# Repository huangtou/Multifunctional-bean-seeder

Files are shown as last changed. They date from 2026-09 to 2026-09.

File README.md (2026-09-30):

# 🌱 多功能豆类播种机

<div align="center">

**基于 STM32F103 的智能履带式播种机 —— 集"行走 · 旋耕 · 开沟 · 播种 · 覆土 · 浇水"于一体**







</div>

---

## 📖 目录

- [项目简介](#-项目简介)
- [演示视频](#-演示视频)
- [项目展示](#-项目展示)
- [功能特性](#-功能特性)
- [整机结构](#️-整机结构)
- [硬件资源与引脚分配](#-硬件资源与引脚分配)
- [蓝牙遥控指令](#-蓝牙遥控指令)
- [软件设计](#-软件设计)
- [目录结构](#-目录结构)
- [快速上手](#-快速上手)
- [开发说明与已知问题](#-开发说明与已知问题)

---

## 📝 项目简介

传统人工播种效率低、株距不均。本项目设计了一款面向豆类作物的**小型多功能自动播种机**，由履带底盘搭载旋耕、开沟、精量排种、浇水等多套执行机构，以 STM32F103 为主控制器，通过蓝牙串口由手机 App 遥控作业，并具备限位开关与光电接近开关双重安全保护。

**主要指标**

| 项目 | 参数 |
| :--- | :--- |
| 主控制器 | STM32F103ZET6（正点原子精英板） |
| 主频 | 72 MHz |
| 行走方式 | 履带式双直流减速电机驱动 |
| 驱动方式 | 直流电机 PWM（10 kHz）+ A4988 步进驱动 |
| 通信方式 | 蓝牙串口 USART2 @ 9600 bps |
| 人机交互 | TFT LCD 实时状态显示 |
| 步进精度 | A4988 细分布进，每脉冲 0.1° |

---

## 🎬 演示视频

### 📺 [点击观看演示视频（B 站 BV14Pas6bEMW）](https://www.bilibili.com/video/BV14Pas6bEMW/?share_source=copy_web&vd_source=6c446a2c349afac65ccd988e4ed9c128)



---

## 🖼️ 项目展示

<table>
  <tr>
    <th align="center">三维模型（SolidWorks）</th>
    <th align="center">实物样机</th>
  </tr>
  <tr>
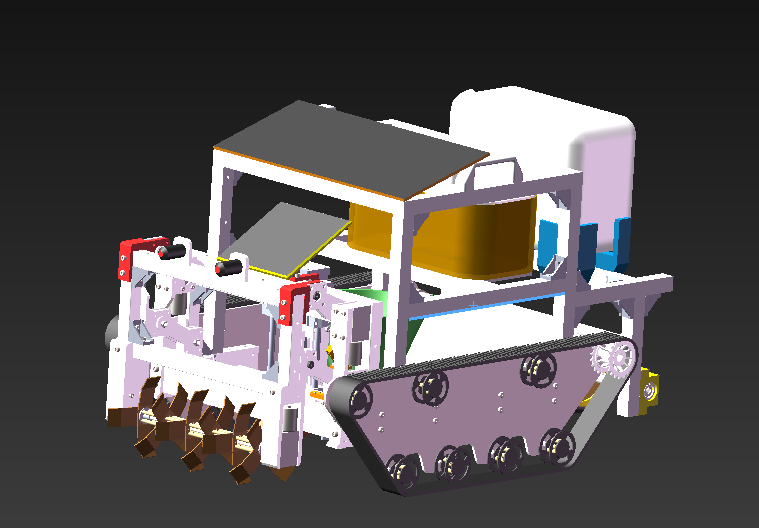
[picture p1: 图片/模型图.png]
三维模型图
    <td align="center"></td>
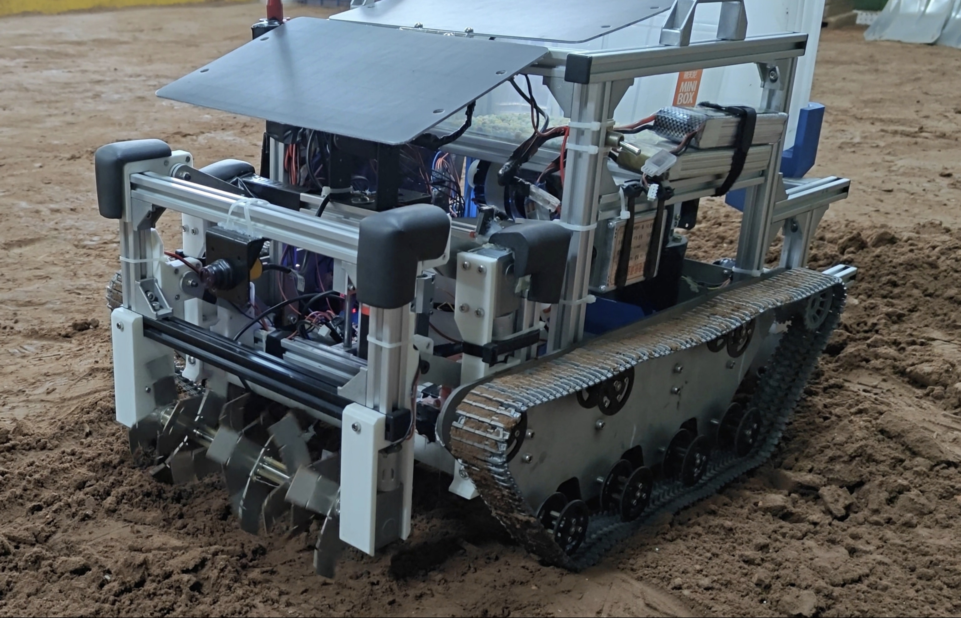
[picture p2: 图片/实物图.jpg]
实物样机图
    <td align="center"></td>
  </tr>
  <tr>
    <td align="center">整机装配体 <code>模型1/装配体.SLDASM</code></td>
    <td align="center">已加工装配完成并通过实地作业测试</td>
  </tr>
</table>

---

## ✨ 功能特性

- 🚜 **履带行走**：双路直流减速电机 + PWM 调速，支持前进 / 后退 / 左转 / 右转（差速转向）
- ⛏️ **旋耕碎土**：独立旋耕刀辊电机，同时可通过丝杆机构整体升降，适应不同耕作深度
- 🪓 **开沟起垄**：步进电机驱动的丝杆升降开沟器，落沟深度精确可控
- 🌰 **精量排种**：42 步进电机 + 组合播种器，由定时器节拍间歇转动实现定量播种
- 💧 **播种后浇水**：水泵 + 喷头 + 水箱机构，随播种同步开启
- 🔄 **覆土回填**：覆土板刮土回填沟槽，一次成型
- 📶 **蓝牙遥控**：手机 App 经 USART2 下发单字节指令，实时切换作业模式
- 🛡️ **多重限位保护**：3 路机械限位开关（PE0~PE2）+ 3 路光电接近开关（PD11~PD13），越程即停
- 🖥️ **状态可视化**：LCD 实时刷新各限位状态、接近开关状态与当前指令码

---

## 🏗️ 整机结构

SolidWorks 源文件位于 `模型1/`，按功能模块组织：

| 装配体文件 | 说明 |
| :--- | :--- |
| `装配体.SLDASM` | 整机总装 |
| `装配底盘.SLDASM` | 履带底盘、承重轮、主动轮、压紧轮 |
| `组合翻土轮.SLDASM` / `装配翻土轮.SLDASM` | 旋耕刀辊与升降保持架（丝杆 8X100 + 直线轴承） |
| `组合开沟器.SLDASM` / `装配开槽器.SLDASM` | 开沟头与升降架板 |
| `组合播种器.SLDASM` / `演示功能播种器.SLDASM` | 储种箱、存种盘、筛种盘、播种管道 |
| `组合浇水机构.SLDASM` | 水箱、水泵、喷头、吸/出水管 |
| `筛种盘/` | 含 4 张工程图（`.DWG`）与对应零件 |
| `装配体.STEP` | 通用 STEP 格式，**无需 SolidWorks 亦可查看** |
| `演示文稿1.pptx` | 项目汇报演示文稿 |

> 零件文件（`.SLDPRT`）共计 100 余个，涵盖机加工件、标准件与钣金件，均按功能命名，可直接用于出图加工。

---

## 🔌 硬件资源与引脚分配

### 主控板

**正点原子 STM32F103ZET6 精英板**（Flash 512 KB，SRAM 64 KB，工程宏：`STM32F10X_HD, USE_STDPERIPH_DRIVER`，启动文件 `startup_stm32f10x_hd.s`）

### 引脚分配总表

| 功能模块 | 方向 IO | PWM / 脉冲 | 说明 |
| :--- | :--- | :--- | :--- |
| **蓝牙串口** | PA2 (TX) / PA3 (RX) | — | USART2，9600 bps，接收中断 |
| **限位开关** | PE0 / PE1 / PE2 | — | 上拉输入，旋耕升降 / 开沟器行程终点检测 |
| **光电接近开关** | PD11 / PD12 / PD13 | — | 上拉输入，前后行进障碍物检测 |
| **履带左轮** | PB14 / PB15（INA） | PA0 — TIM2_CH1 | 直流减速电机正反转 + 调速 |
| **履带右轮** | PB13 / PB12（INB） | PA1 — TIM2_CH2 | 直流减速电机正反转 + 调速 |
| **旋耕器升降电机** | PA4 / PA5 | PA6 — TIM3_CH1 | 丝杆升降机构 |
| **旋耕刀辊电机** | PC4 / PC5 | PA7 — TIM3_CH2 | 旋耕碎土主电机 |
| **开沟器升降步进** | PC8 (STEP) / PC9 (DIR) | — | A4988 驱动器 |
| **播种步进电机** | PF14 (STEP) / PF15 (DIR) | — | A4988 驱动器 |
| **浇水水泵电机** | PF4 / PF5 | PA10 — TIM1_CH3 | 水泵启停 |
| **备用步进通道** | PF12/PF13、PC10/PC11 | — | 预留扩展 |
| **调试串口** | PA9 (TX) / PA10 (RX) | — | USART1 @ 9600，打印调试（⚠️ RX 脚 PA10 与水泵 PWM 复用，见文末「开发说明与已知问题」） |

> 完整 IO 说明亦见原始备份文件：`keil代码/README.TXT`

### 定时器资源分配

| 定时器 | 用途 | 配置 |
| :--- | :--- | :--- |
| TIM1 | 浇水水泵 PWM 输出 | 周期 8000-1，预分频 9-1 → 1 kHz |
| TIM2 | 左右履带电机 PWM | 同上 |
| TIM3 | 旋耕升降 / 旋耕刀辊 PWM | 同上 |
| TIM5 | 播种节拍定时中断 | 预分频 7200-1，周期 10000-1 → **1 s** 触发一次排种 |
| SysTick | `delay_ms()` / `delay_us()` 软件延时基准 | — |

---

## 📲 蓝牙遥控指令

主控串口 2 中断接收单字节数据存入 `temp1`，主循环据此切换作业状态：

| 指令值 | 动作 | 保护条件 |
| :---: | :--- | :--- |
| `0` | 使能播种定时器时钟 | — |
| `1` | 履带前进（双轮正转） | 前方光电开关检测到障碍（`gd1 == 0`）即停 |
| `2` | 履带后退（双轮反转） | 后方光电开关检测到障碍（`gd2 == 0`）即停 |
| `3` | **急停**：履带、旋耕、水泵、定时器全部停止 | — |
| `4` | 旋耕刀辊启动 | — |
| `5` | 旋耕器下降 | 触下限位（`num0 == 0`）自动停 |
| `6` | 旋耕器上升 | 触上限位（`num1 == 0`）自动停 |
| `7` | 浇水水泵启动 | — |
| `8` | 开沟器下降 | — |
| `9` | 开沟器上升 | 触上限位（`num2 == 0`）自动停 |
| `16` | 启动播种定时器（TIM5），进入定量排种节拍 | — |
| `17` | 左转（左轮反转 / 右轮正转） | — |
| `18` | 右转（左轮正转 / 右轮反转） | — |

**典型作业流程**

```
1 → 前进到作业区          → 3 停车
5 → 旋耕器下降至耕作深度  → 4 开启旋耕
8 → 开沟器下降至开沟深度  → 16 启动排种节拍
1 → 边前进边播种          → 7 同步浇水
9 / 6 → 作业结束收起机构  → 3 全部停止
```

---

## 💻 软件设计

### 主程序流程

```
main()
 ├─ delay_init()            延时基准初始化
 ├─ uart_init(9600)         USART1 调试串口
 ├─ LCD_Init()              TFT 屏初始化
 ├─ USART2_Init()           蓝牙串口 + 接收中断
 ├─ AIN_GPIO_Config / GENERAL_TIM_Init           ← TIM2 履带
 ├─ AIN_GPIO_Config2 / GENERAL_TIM_Init2         ← TIM3 旋耕
 ├─ AIN_GPIO_Config3 / GENERAL_TIM_Init3         ← TIM1 水泵
 ├─ MOTOR_Init()            A4988 步进 IO
 ├─ Xianwei_init()          限位开关 IO
 └─ while(1)
     ├─ 读取三路限位 + 两路光电 → LCD 实时显示
     └─ switch(temp1) 执行对应动作（含限位急停判断）
```

### 源码文件说明

| 文件 | 作用 |
| :--- | :--- |
| `USER/main.c` | 主循环状态机、传感器读取、LCD 显示、动作执行与安全互锁 |
| `USER/openmv.c/.h` | USART2 初始化与接收中断，蓝牙指令解码（**注：文件名为历史遗留，本项目实际接蓝牙模块**） |
| `USER/Motor_PWM.c/.h` | TIM2 履带双电机 PWM 驱动与正反转控制 |
| `USER/motor2.c/.h` | TIM3 旋耕升降 + 旋耕刀辊 PWM 驱动 |
| `USER/motor3.c/.h` | TIM1 水泵 PWM 驱动 |
| `USER/Stepper_A4988.c/.h` | A4988 步进脉冲生成，`Stepgo(电机号, 方向, 脉冲数)` |
| `USER/Stepper_motor.c` / `Stepper_motor2.c` | 备选的相序式步进驱动方案（当前未在主控流程中使用） |
| `USER/tim.c/.h` | TIM5 播种节拍中断，每次中断调用 `Stepgo(2, 0, 1500)` 排种 |
| `USER/xianwei.c/.h` | PE0~PE2 机械限位开关读取 |
| `USER/gd.c/.h` | PD11~PD13 光电接近开关读取 |
| `SYSTEM/delay`、`sys`、`usart` | 正点原子系统级延时、位带操作、调试串口 |
| `HARDWARE/LCD`、`LED`、`KEY` | TFT 显示、指示灯、按键外设驱动 |

### 步进电机驱动

`Stepgo(num, dir, step)` 通过 DIR 电平设定转向，再输出指定数量的 STEP 脉冲，脉冲宽度由 `delay_us()` 控制：

| 电机编号 | STEP / DIR | 用途 | 脉冲宽度 |
| :---: | :--- | :--- | :--- |
| 1 | PF12 / PF13 | 预留 | 200 µs |
| 2 | PF14 / PF15 | **播种排种** | 1000 µs |
| 3 | PC8 / PC9 | **开沟器升降** | 500 µs |
| 4 | PC10 / PC11 | 预留 | 1 ms |

### LCD 显示内容

LCD 上实时刷新 6 个状态量，方便现场排查传感器接线与机构到位情况：

```
限位0 / 限位1 / 限位2        ← PE0 / PE1 / PE2
当前指令 temp1               ← 蓝牙最新下发
光电1 / 光电2                ← PD11 / PD12
```

---

## 📁 目录结构

```
多功能豆类播种机/
├── 📄 README.md                 # 本说明文档
├── 📄 .gitignore                # 忽略编译产物与软件临时文件
│
├── 🖼️ 图片/                      # README 用图（模型渲染图、实物图）
├── 📷 样机照片/                  # 实物照片原图
│
├── 🎬 播种机演示视频.mp4         # 演示视频源文件（约 68 MB，建议不提交 Git）
│                                 #   在线观看：https://www.bilibili.com/video/BV14Pas6bEMW
│
├── 🧊 模型1/                     # SolidWorks 三维模型
│   ├── 装配体.SLDASM            # 整机总装
│   ├── 装配体.STEP              # 通用 STEP，无 SW 也可打开
│   ├── *.SLDPRT                 # 100+ 零件文件
│   ├── 筛种盘/                  # 含 DWG 工程图
│   └── 演示文稿1.pptx           # 项目汇报 PPT
│
└── 💾 keil代码/                  # STM32 Keil MDK 工程
    ├── USER/                    # 应用代码与工程文件（LCD.uvprojx）
    ├── HARDWARE/                # 外设驱动：LED / KEY / LCD
    ├── SYSTEM/                  # 系统底层：delay / sys / usart
    ├── STM32F10x_FWLib/         # ST 标准外设库
    ├── CORE/                    # 内核与启动文件
    ├── OBJ/                     # 编译输出（已 gitignore）
    └── README.TXT               # 原始 IO 与外设分配说明
```

---

## 🚀 快速上手

### 1. 编译与下载

1. 安装 **Keil MDK5**（需安装 STM32F1xx Device Family Pack）
2. 打开 `keil代码/USER/LCD.uvprojx`
3. Target Options → Device 选择 **STM32F103ZE**，C/C++ Define 保持 `STM32F10X_HD, USE_STDPERIPH_DRIVER`
4. 通过 **J-Link / ST-Link** SWD 接口连接板子，点击 Load 下载程序

### 2. 蓝牙连接

1. 蓝牙模块 TXD / RXD 交叉接至 **PA3(RX) / PA2(TX)**，波特率 **9600**（8N1，无流控）
2. 手机上打开蓝牙串口助手 App，配对模块
3. 以**十六进制 / 数值模式**发送上述指令码（如发送 `16` 启动排种流程图所示流程）

> ⚠️ 请勿以 ASCII 字符模式发送，代码按接收到的字节数值直接判别。

### 3. 查看三维模型

- 安装 SolidWorks：打开 `模型1/装配体.SLDASM`
- 无 SolidWorks：任意三维/CAD 软件打开 `模型1/装配体.STEP`

---

## ⚠️ 开发说明与已知问题

- **`openmv.c` 命名误导**：该文件实际实现的是 USART2 蓝牙接收，OpenMV 视觉模块并未接入，建议后续重命名为 `bluetooth.c`。
- **冗余文件**：`Stepper_motor.c` / `Stepper_motor2.c` 为早期 ULN2003 相序驱动方案，已被 A4988 方案替代，暂未从工程移除。
- **主循环阻塞**：`Stepgo()` 内部使用阻塞式 `delay_us()`，输出脉冲数较多时会长时间占用主循环，导致蓝牙指令响应延迟（如 `Stepgo(2,0,1500)` 约需 3 s）。建议改为定时器比较输出或 DMA 方式产生脉冲。
- **PA10 引脚冲突**：`uart_init()` 将 USART1_RX 配置在 PA10，而浇水水泵 PWM（TIM1_CH3）同样使用 PA10，两者存在复用冲突，实际测试中需二选一或重映射。
- **`GD_Value()` 返回值未全覆盖**：`i` 取其他值时函数无返回值，属潜在隐患。
- **中文注释编码**：源码为 GBK 编码上传，建议保持原编码以避免乱码。

**后续改进方向**

- [ ] 引入编码器 + PID 实现履带速度闭环与直线行驶纠偏
- [ ] 增加 OpenMV 视觉模块实现自动循垄导航
- [ ] 步进脉冲改为定时器 DMA/比较输出，释放 CPU
- [ ] 增加 Wi-Fi 模块接入物联网平台，实现远程作业调度
- [ ] 补充电源管理与电量检测

---

## 🧰 开发环境

| 类别 | 工具 / 型号 |
| :--- | :--- |
| MCU | STM32F103ZET6（正点原子精英板） |
| IDE | Keil MDK5（ARMCC 5） |
| 固件库 | STM32F10x Standard Peripheral Library |
| 下载器 | J-Link / ST-Link（SWD） |
| 串口调试 | 蓝牙串口助手 App、SSCOM |
| 三维设计 | SolidWorks |

---

## 📄 许可

<div align="center">

本项目为课程设计 / 毕业设计作品，仅供学习与交流使用。

⭐ 如果这个项目对你有帮助，欢迎点个 Star！

</div>

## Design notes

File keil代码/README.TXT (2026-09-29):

控制基于正点原子精英板
蓝牙串口：USART2  PA2 PA3
限位开关：PE0 PE1 PE2
光电接近开关：PD11 PD12 PD13
履带电机： INA :  PB14 PB15      PWM PA0
		   INB ：PB13 OB12     PWM PA1
旋耕器上下电机：PA4 PA5 PWM PA6
旋耕电机：PC4 PC5 PWM PA7
开沟器上下步进电机： STEP -PC8   DIR -PC9  （采用A4988步进电机驱动器）
浇水电机：PF4 PF5   PWM PA10
播种步进电机：STEP - PF14   DIR  - PF15（采用A4988步进电机驱动器）

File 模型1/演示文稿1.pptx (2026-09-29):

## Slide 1

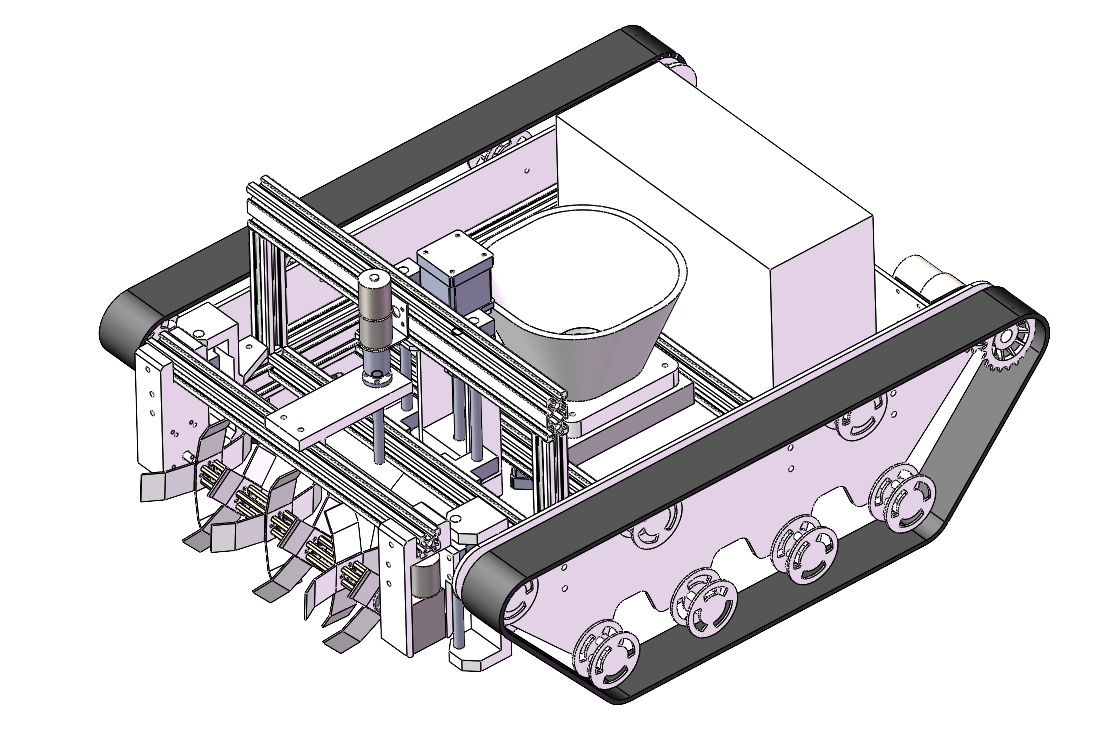
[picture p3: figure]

5

4

6

2

7

3

1

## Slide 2

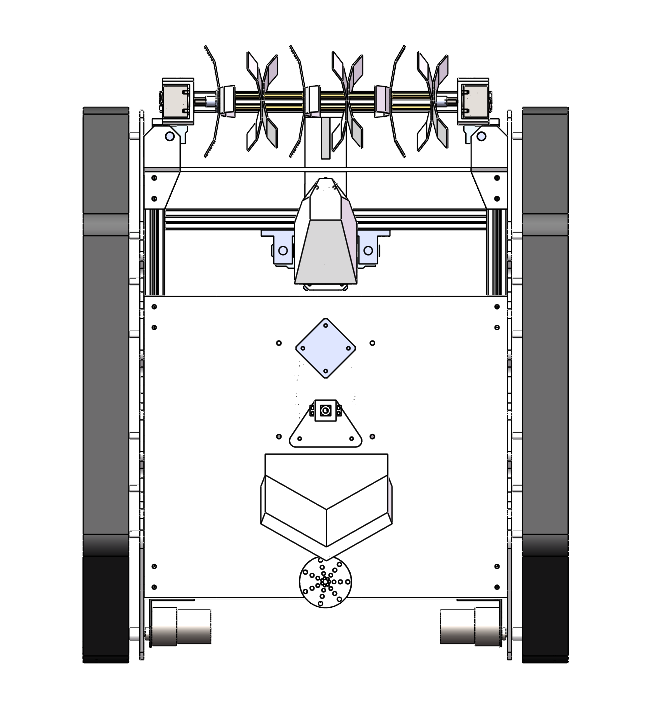
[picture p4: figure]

9

8

10

11

12

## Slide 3

触摸屏

运动机构

光幕传感器

直流电机驱动电路

翻土轮升降机构

陀螺仪传感器

STM32

限位开关

浇水机构

按键

挖槽器升降机构

WiFi

步进电机驱动电路

播种器驱动机构

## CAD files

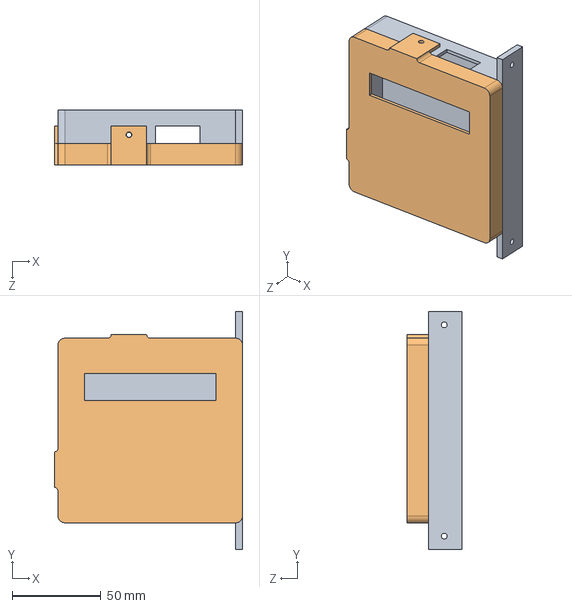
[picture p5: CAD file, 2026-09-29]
模型1/新建文件夹/装配体2.SLDASM
106.0 x 134.0 x 31.0 mm
主控盒底
主控盒盖

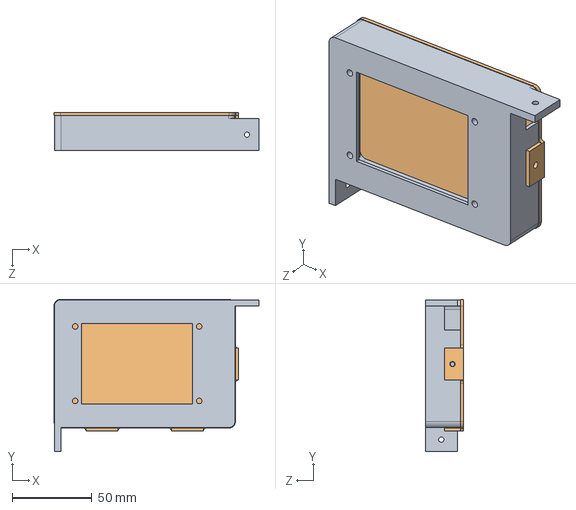
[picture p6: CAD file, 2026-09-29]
模型1/新建文件夹/装配体1.SLDASM
128.2 x 95.2 x 24.0 mm
触摸面板2
触摸面板后盖2

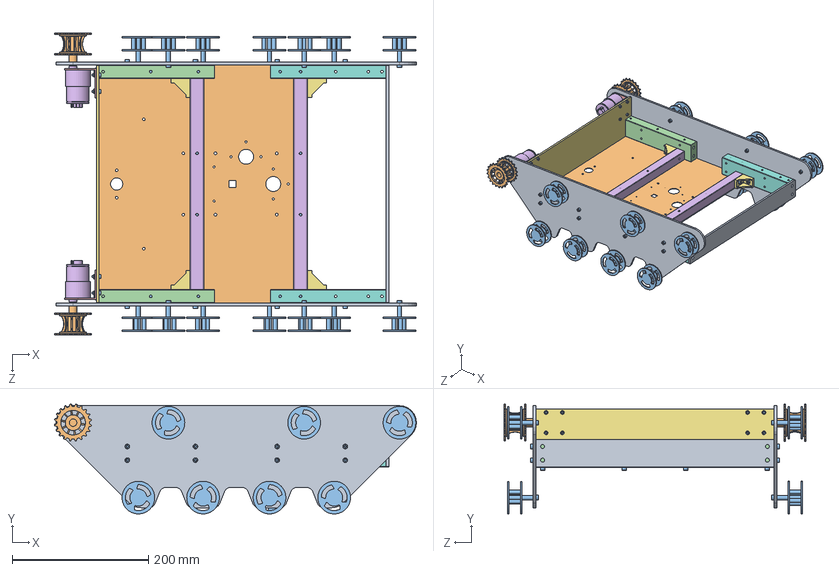
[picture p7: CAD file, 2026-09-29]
模型1/装配底盘.SLDASM
531.6 x 161.3 x 443.0 mm
轮板 x 2
主动轮 x 2
承重轮 x 14
轮板边梁1 x 2
电机支架 x 2
减速电机 x 2
电机固定板
轮板边梁2 x 2
后板
底板
hexagon socket head cap screws gb x 60
hexagon socket button head screws gb x 4
hex nuts, style 1-grades ab gb x 8
底盘横梁 x 2
角码 x 4

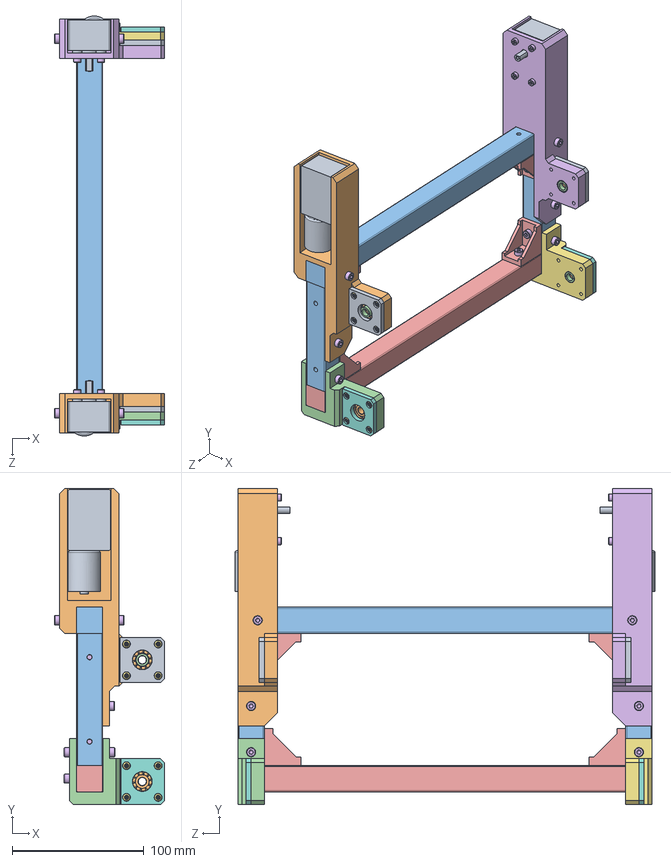
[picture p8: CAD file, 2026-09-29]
模型1/装配翻土轮保持架.SLDASM
83.8 x 239.8 x 318.4 mm
蜗杆减速电机 x 2
翻土轮电机架
翻土轮下横梁
翻土轮上轴承座
翻土轮上横梁
翻土轮电机架2
翻土轮上轴承座2
轴承盖 x 2
轴承盖2 x 2
deep groove ball bearings gb x 4
翻土轮竖梁 x 2
轴承垫 x 6
角码 x 4
hexagon socket head cap screws gb x 29
hexagon socket button head screws gb x 16
hex nuts, style 1-grades ab gb

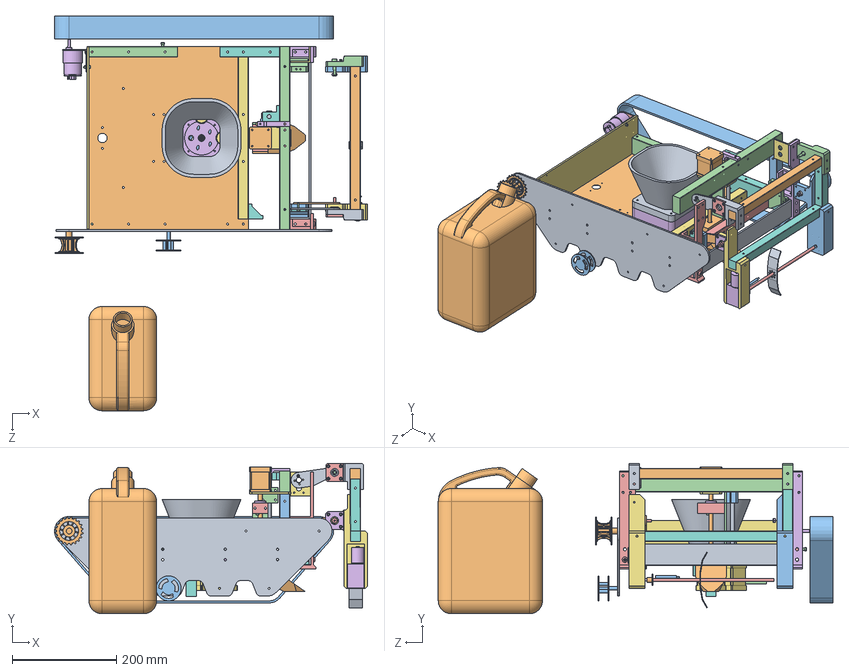
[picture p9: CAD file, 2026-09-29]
模型1/演示功能播种器.SLDASM
600.1 x 288.5 x 756.5 mm
播种器
42步进电机 x 2
播种管道
deep groove ball bearings gb x 2
薄垫片
hexagon socket head cap screws gb
hex nuts, style 1-grades ab gb
光幕传感器 x 2
沙枣种 x 5

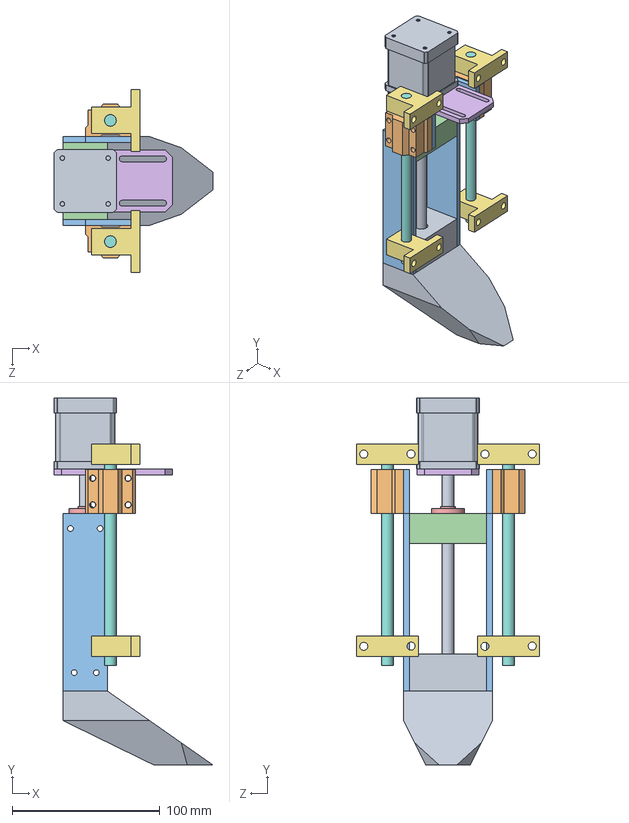
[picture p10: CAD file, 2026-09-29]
模型1/挖槽器装配.SLDASM
107.6 x 248.3 x 124.0 mm
开槽头
8直线轴承座 x 2
挖槽升降架板 x 2
挖槽螺母座
丝杆螺母
42电机平架
光轴支架 x 4
光轴8X150 x 2
42丝杆步进电机

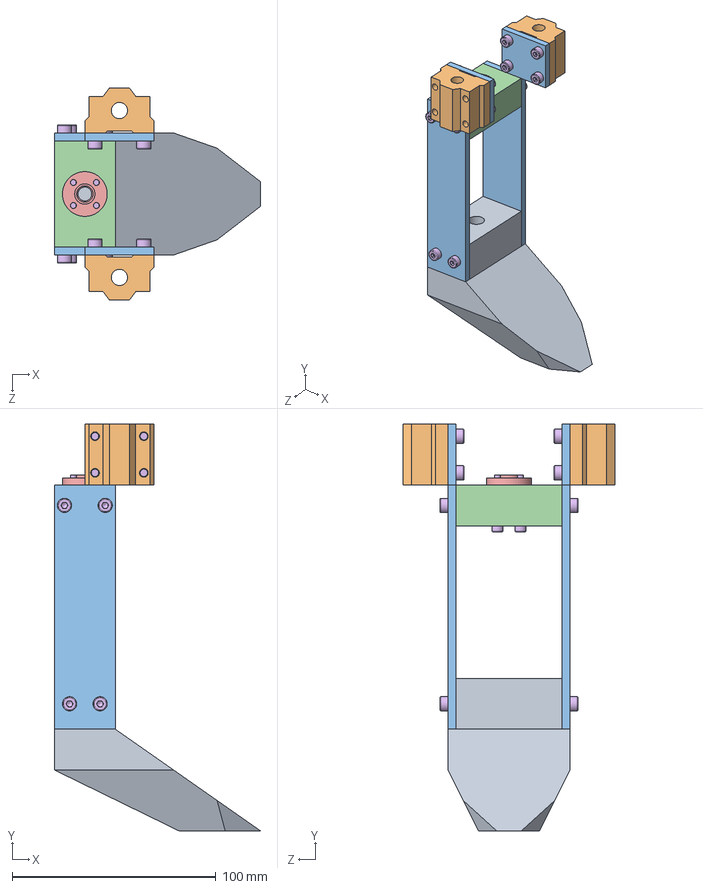
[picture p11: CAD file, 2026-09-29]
模型1/装配开槽器.SLDASM
101.4 x 200.0 x 104.0 mm
开槽头
8直线轴承座 x 2
挖槽升降架板 x 2
挖槽螺母座
丝杆螺母
hexagon socket head cap screws gb x 20

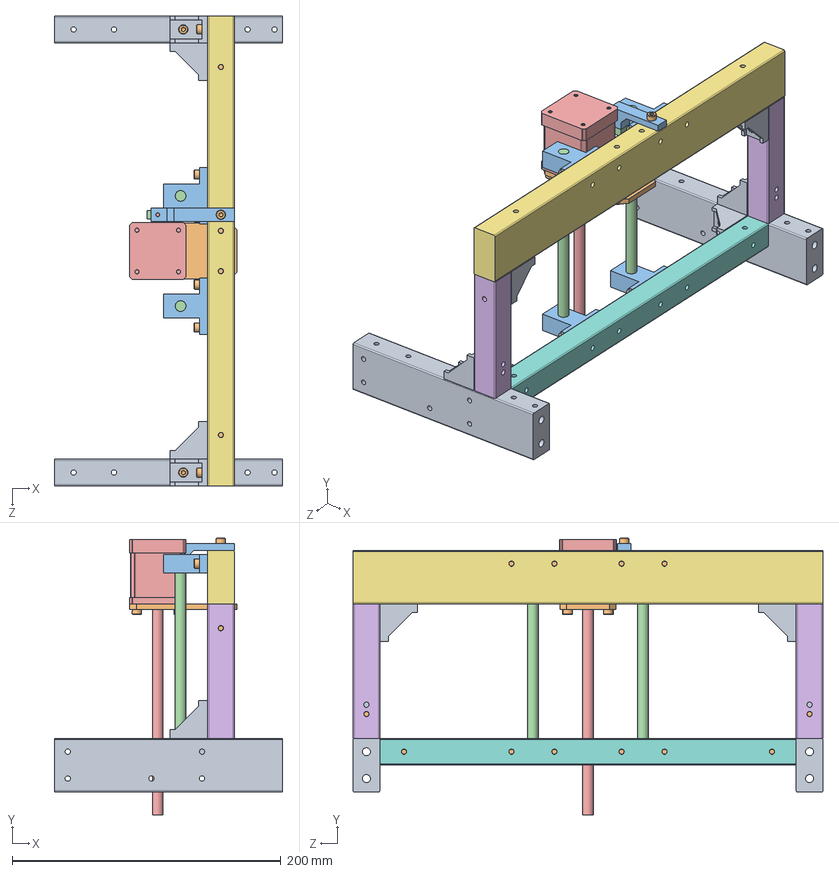
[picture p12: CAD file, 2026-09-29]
模型1/装配开槽器保持架.SLDASM
170.0 x 206.0 x 350.0 mm
轮板边梁2 x 2
42电机平架
光轴支架 x 4
光轴8X150 x 2
42丝杆步进电机
升降竖梁 x 2
开槽器上横梁
开槽器下横梁
角码 x 6
hexagon socket head cap screws gb x 27
开沟器限位块
接近开关
hexagon socket countersunk head screws gb

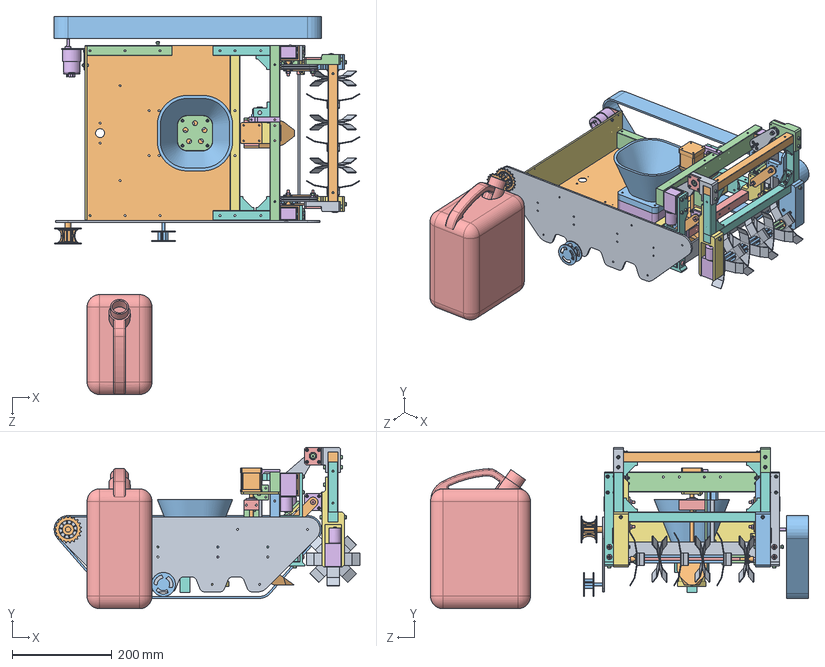
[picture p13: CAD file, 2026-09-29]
模型1/组合翻土轮.SLDASM
611.9 x 323.1 x 756.5 mm
轮板边梁2 x 2
后板
翻土轮叶片 x 12
法兰联轴器6mm x 6
铜柱38+6 x 16
铜柱38 x 4
翻土轮轴
hexagon socket head cap screws gb x 81
蜗杆减速电机 x 4
翻土轮电机架
翻土轮下横梁
翻土轮上轴承座
翻土轮上横梁
翻土轮电机架2
翻土轮上轴承座2
轴承盖 x 2
轴承盖2 x 2
deep groove ball bearings gb x 6
翻土轮竖梁 x 2
轴承垫 x 10
角码 x 6
hexagon socket button head screws gb x 28
hex nuts, style 1-grades ab gb x 23
开槽器下横梁
翻土轮上轴承臂上 x 4
翻土轮上轴承臂下 x 4
法兰盘垫 x 2
轴肩限位螺栓16 x 2
轴肩限位螺栓20 x 4
翻土轮上轴承座下
翻土轮上轴承座下2
翻土轮光轴座
翻土轮光轴座2
蜗杆减速电机支架 x 2
轴承盖3 x 2
接近开关 x 2
翻土轮上限位固定块
翻土轮下限位固定块
hexagon socket countersunk head screws gb x 2

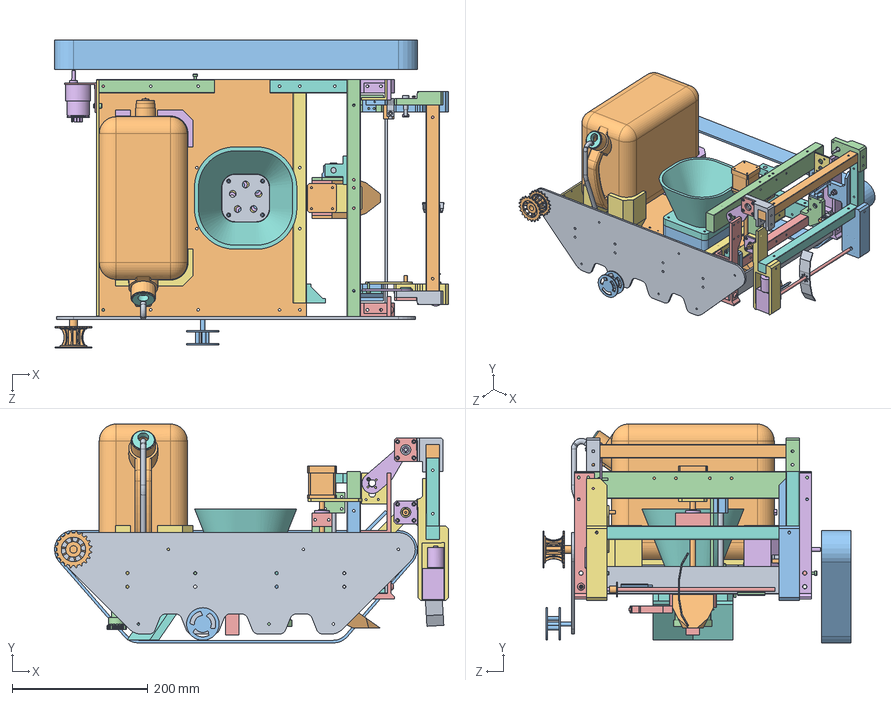
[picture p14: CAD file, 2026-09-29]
模型1/组合浇水机构.SLDASM
581.2 x 323.0 x 455.0 mm
水箱
喷头
喷头接口
水箱支架1
水箱支架2
水箱内塞
吸水管
水泵
出水管

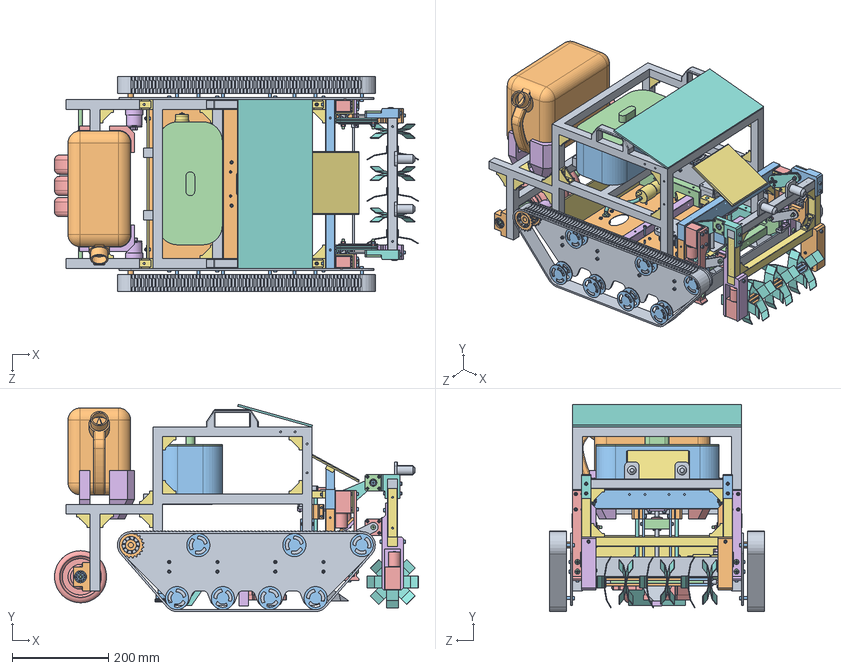
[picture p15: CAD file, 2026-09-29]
模型1/装配体.SLDASM
755.1 x 430.0 x 447.0 mm
轮板 x 2
主动轮 x 2
承重轮 x 14
轮板边梁1 x 2
电机支架 x 2
减速电机 x 2
电机固定板
轮板边梁2 x 2
后板
底板
hexagon socket head cap screws gb x 211
hexagon socket button head screws gb x 32
hex nuts, style 1-grades ab gb x 34
底盘横梁 x 2
角码 x 32
翻土轮叶片 x 12
法兰联轴器6mm x 6
铜柱38+6 x 16
铜柱38 x 4
翻土轮轴
蜗杆减速电机 x 4
翻土轮电机架
翻土轮下横梁
翻土轮上轴承座
翻土轮上横梁
翻土轮电机架2
翻土轮上轴承座2
轴承盖 x 2
轴承盖2 x 2
deep groove ball bearings gb x 8
翻土轮竖梁 x 2
轴承垫 x 10
开槽头
8直线轴承座 x 2
挖槽升降架板 x 2
挖槽螺母座
丝杆螺母
42电机平架
光轴支架 x 4
光轴8X150 x 2
42丝杆步进电机
升降竖梁 x 2
开槽器上横梁
开槽器下横梁
开沟器限位块
接近开关 x 3
hexagon socket countersunk head screws gb x 3
翻土轮上轴承臂上 x 4
翻土轮上轴承臂下 x 4
法兰盘垫 x 2
轴肩限位螺栓16 x 2
轴肩限位螺栓20 x 4
42步进电机 x 2
播种管道
存种盘
筛种盘
播种盖板
水箱
翻土轮上轴承座下
翻土轮上轴承座下2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

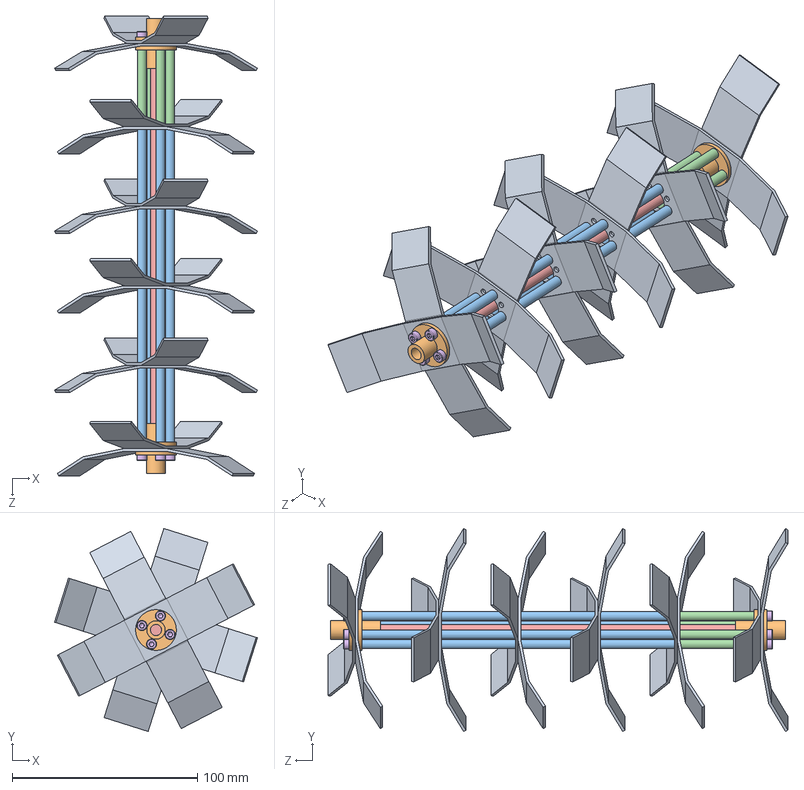
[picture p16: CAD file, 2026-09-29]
模型1/装配翻土轮.SLDASM
109.7 x 109.7 x 248.5 mm
翻土轮叶片 x 12
法兰联轴器6mm x 4
铜柱38+6 x 16
铜柱38 x 4
翻土轮轴
hexagon socket head cap screws gb x 8

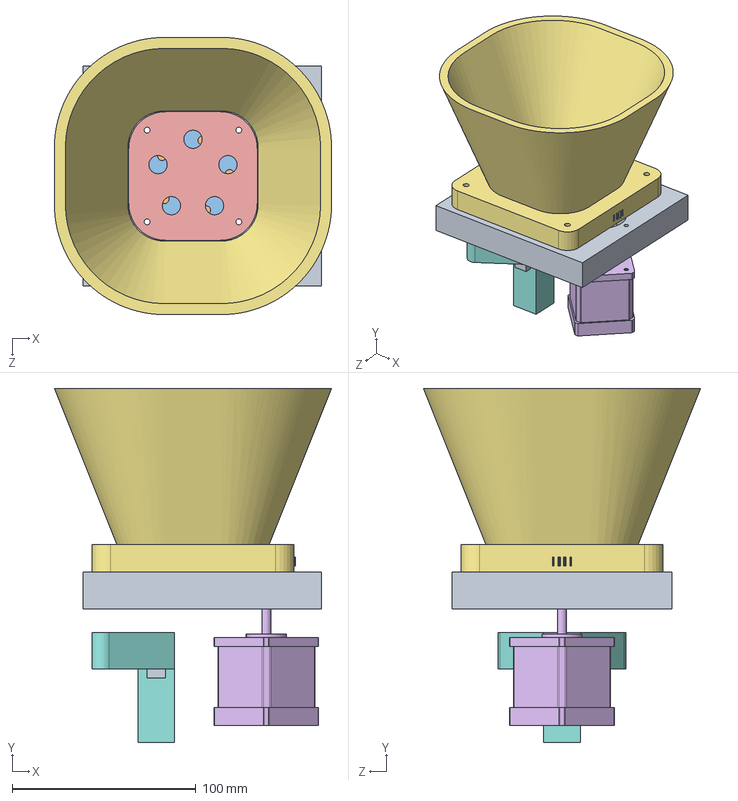
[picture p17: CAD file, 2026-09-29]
模型1/播种器装配.SLDASM
151.0 x 192.8 x 151.0 mm
播种器
存种盘
筛种盘
导轮
播种盖板
42步进电机
储种箱
播种管道
激光对射传感器 x 2
spur gear_gb

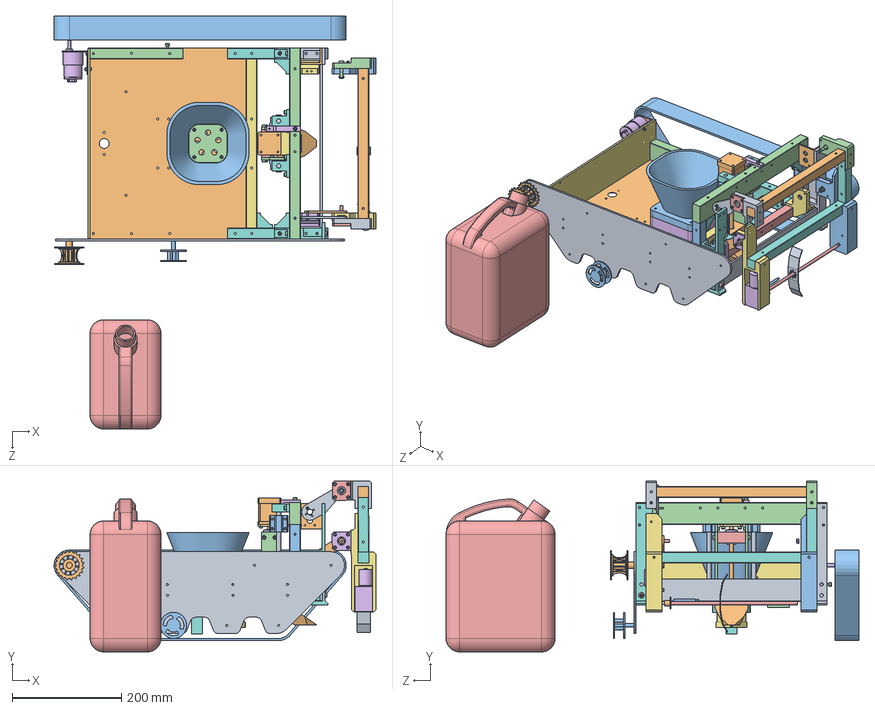
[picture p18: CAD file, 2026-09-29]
模型1/组合开沟器.SLDASM
589.7 x 312.9 x 756.5 mm
轮板边梁2 x 2
开槽头
8直线轴承座 x 2
挖槽升降架板 x 2
挖槽螺母座
丝杆螺母
hexagon socket head cap screws gb x 48
42电机平架
光轴支架 x 4
光轴8X150 x 2
42丝杆步进电机
升降竖梁 x 2
开槽器上横梁
开槽器下横梁
角码 x 6
开沟器限位块 x 2
接近开关 x 2
hexagon socket countersunk head screws gb x 2

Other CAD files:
模型1/组合播种器.SLDASM
模型1/丝杆8X100.SLDPRT
模型1/存种盘/存种盘21.DWG
模型1/筛种盘/筛种盘中.SLDPRT
模型1/42丝杆步进电机.sldprt
模型1/42步进电机.sldprt
模型1/42电机平架.SLDPRT
模型1/5-8联轴器.SLDPRT
模型1/8直线轴承座.SLDPRT
模型1/丝杆滑块.SLDPRT
模型1/丝杆螺母.SLDPRT
模型1/主动轮.SLDPRT
模型1/主动齿轮.SLDPRT
模型1/主动齿轮2.SLDPRT
模型1/主控盒底.SLDPRT
模型1/主控盒盖.SLDPRT
模型1/从动轮支撑垫.SLDPRT
模型1/储种箱.SLDPRT
模型1/光幕传感器.SLDPRT
模型1/光幕传感器控制器.SLDPRT
模型1/光纤1.SLDPRT
模型1/光纤2.SLDPRT
模型1/光轴8X130.SLDPRT
模型1/光轴8X150.SLDPRT
模型1/光轴支架.SLDPRT
模型1/减速电机.SLDPRT
模型1/出水管.SLDPRT
模型1/升降竖梁.SLDPRT
模型1/压紧轮.SLDPRT
模型1/压紧轮轴.SLDPRT
模型1/后板.SLDPRT
模型1/吸水管.SLDPRT
模型1/喷头.SLDPRT
模型1/喷头接口.SLDPRT
模型1/外框架.SLDPRT
模型1/太阳能板2.SLDPRT
模型1/存种盘.SLDPRT
模型1/存种盘/存种盘1.DWG
模型1/存种盘/存种盘22.DWG
模型1/小太阳能板.SLDPRT
模型1/履带.SLDPRT
模型1/履带片.SLDPRT
模型1/底板.SLDPRT
模型1/底盘横梁.SLDPRT
模型1/开槽器上横梁.SLDPRT
模型1/开槽器下横梁.SLDPRT
模型1/开槽头.SLDPRT
模型1/开沟器限位块.SLDPRT
模型1/承重轮.SLDPRT
模型1/挖槽升降架板.SLDPRT
模型1/挖槽螺母座.SLDPRT
模型1/接近开关.SLDPRT
模型1/播种器.SLDPRT
模型1/播种盖板.SLDPRT
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

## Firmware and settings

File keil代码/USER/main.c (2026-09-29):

#include "led.h"
#include "delay.h"
#include "sys.h"
#include "usart.h"
#include "lcd.h"
#include "openmv.h"
#include "Motor_PWM.h"
#include "motor2.h"
#include "motor3.h"
#include "tim.h"
#include "Stepper_A4988.h"
#include "xianwei.h"
#include "gd.h"
uint8_t num0;
uint8_t num1;
uint8_t num2;
uint8_t gd1,gd2;
 int main(void)
 { 
	u8 x=0;
	u8 lcd_id[12];			//存放LCD ID字符串	
	delay_init();	    	 //延时函数初始化	  
	uart_init(9600);	 	//串口初始化为9600
 	LCD_Init();
	USART2_Init();//串口初始化
	sprintf((char*)lcd_id,"LCD ID:%04X",lcddev.id);//将LCD ID打印到lcd_id数组。	
	LCD_Clear(BLACK);
	AIN_GPIO_Config();
	GENERAL_TIM_Init();
	AIN_GPIO_Config2();
	GENERAL_TIM_Init2();
	AIN_GPIO_Config3();
	GENERAL_TIM_Init3();
	MOTOR_Init();
	GENERAL_TIM_Change_PULSE3(1, 0, 100);
	Xianwei_init();
	//LCD_ShowNum(30,10,temp1,3,24);
	RCC_APB1PeriphClockCmd(RCC_APB1Periph_TIM5, DISABLE);//播种定时器关闭
  while(1) 
	{	
		num0=read_Value(0);
		num1=read_Value(1);
		num2=read_Value(2);
		gd1=GD_Value(0);
		gd2=GD_Value(1);
		LCD_ShowNum(30,10,num0,3,24);
		LCD_ShowNum(30,30,num1,3,24);
		LCD_ShowNum(30,50,num2,3,24);
		LCD_ShowNum(30,70,temp1,3,24);
		LCD_ShowNum(30,90,gd1,3,24);
		LCD_ShowNum(30,110,gd2,3,24);
		if(temp1==1)//履带前进
		{
			if(gd1==1)
			{
				GENERAL_TIM_Change_PULSE(1, -1, 100);//PB14 PB15  PWM PA0
				GENERAL_TIM_Change_PULSE(2, -1, 100);//PB13 PB12  PWM PA1
			}
			else
			{
				GENERAL_TIM_Change_PULSE(1, 0, 0);//PB14 PB15  PWM PA0
				GENERAL_TIM_Change_PULSE(2, 0, 0);//PB13 PB12  PWM PA1
			}
		}
		if(temp1==2)//履带后退
		{
			//my_dir=-1;
			if(gd2==1)
			{
				GENERAL_TIM_Change_PULSE(1, 1, 100);
				GENERAL_TIM_Change_PULSE(2, 1, 100);
			}
			else
			{
				GENERAL_TIM_Change_PULSE(1, 0, 0);
				GENERAL_TIM_Change_PULSE(2, 0, 0);
			}
			
		}
		
		if(temp1==3)//停止
		{
			GENERAL_TIM_Change_PULSE(1, 0, 100);
			GENERAL_TIM_Change_PULSE(2, 0, 100);//前进停
			
			GENERAL_TIM_Change_PULSE2(1, 0, 100);//旋耕器上升停止
			GENERAL_TIM_Change_PULSE2(2, 0, 100);//旋耕停
			
			GENERAL_TIM_Change_PULSE3(1, 0, 0);//抽水停止
			
			RCC_APB1PeriphClockCmd(RCC_APB1Periph_TIM5, DISABLE);
		}
		
		
		if(temp1==4)//开旋耕
		{
			
			GENERAL_TIM_Change_PULSE2(1, -1, 100);//PC45  PWM  PA7
			//GENERAL_TIM_Change_PULSE2(1, 1, 100);//PA45  PWM  PA6
		}
		if(temp1==5)
		{
			
			if(num0==1)
			{
				GENERAL_TIM_Change_PULSE2(2, -1, 100);//旋耕器下降PA45  PWM  PA6
			}
			else
			{
				GENERAL_TIM_Change_PULSE2(2, 0, 0);
			}
			
		}
		if(temp1==6)
		{
			
			if(num1==1)
			{
				GENERAL_TIM_Change_PULSE2(2, 1, 100);//旋耕器上降PA4 5
			}
			else
			{
				GENERAL_TIM_Change_PULSE2(2, 0, 0);
			}
			
		}
		
		if(temp1==0)
		{
			RCC_APB1PeriphClockCmd(RCC_APB1Periph_TIM5, ENABLE);
		}
		if(temp1==7)
		{
			GENERAL_TIM_Change_PULSE3(1, 1, 100);
		}
		if(temp1==8)//开沟器下（长按）
		{
				Stepgo(1,1,2000);
		}
		if(temp1==9)//开沟器上（长按）
		{
			if(num2==1)
			{
				Stepgo(1,0,2000);
			}
			else
			{
				Stepgo(1,0,0);
			}
				
		}
		if(temp1==16)//播种定时器开
		{
			tim_Init();//播种定时器中断
		}
		if(temp1==17)//左转
		{
			GENERAL_TIM_Change_PULSE(1, 1, 100);
			GENERAL_TIM_Change_PULSE(2, -1, 100);
		}
		if(temp1==18)//右转
		{
			GENERAL_TIM_Change_PULSE(1, -1, 100);
			GENERAL_TIM_Change_PULSE(2, 1, 100);
		}
	}
}

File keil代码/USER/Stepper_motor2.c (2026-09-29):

#include "stm32f10x.h"                  // Device header
#include "Stepper_motor2.h"

void Driver_Init(void)
{
 GPIO_InitTypeDef  GPIO_InitStructure;
 	
 RCC_APB2PeriphClockCmd(RCC_APB2Periph_GPIOC|RCC_APB2Periph_GPIOG, ENABLE);	 //使能PC,PG端口时钟
	
 GPIO_InitStructure.GPIO_Pin = GPIO_Pin_1|GPIO_Pin_2|GPIO_Pin_3|GPIO_Pin_4;			 
 GPIO_InitStructure.GPIO_Mode = GPIO_Mode_Out_PP; 		 //推挽输出
 GPIO_InitStructure.GPIO_Speed = GPIO_Speed_50MHz;		 //IO口速度为50MHz
 GPIO_Init(GPIOC, &GPIO_InitStructure);					 
	
 GPIO_InitStructure.GPIO_Pin = GPIO_Pin_1|GPIO_Pin_2|GPIO_Pin_3|GPIO_Pin_4;			 
 GPIO_InitStructure.GPIO_Mode = GPIO_Mode_Out_PP; 		 //推挽输出
 GPIO_InitStructure.GPIO_Speed = GPIO_Speed_50MHz;		 //IO口速度为50MHz
 GPIO_Init(GPIOG, &GPIO_InitStructure);					 
	
	
 GPIO_ResetBits(GPIOC,GPIO_Pin_1|GPIO_Pin_2|GPIO_Pin_3|GPIO_Pin_4);	//ENable使能口
 GPIO_ResetBits(GPIOG,GPIO_Pin_1|GPIO_Pin_2|GPIO_Pin_3|GPIO_Pin_4);	//dir方向口
}

//TIMx->PSC寄存器设置为72-1，则TIMx->ARR寄存器值为156，这样定时器的频率就是6400HZ
void Stepper_TIM_Init(u16 per,u16 psc)//per==arr
{
	GPIO_InitTypeDef	GPIO_InitStructrue;    //GPIO结构体定义
	TIM_TimeBaseInitTypeDef  TIM_TimeBaseInitStructrue;    //时钟结构体定义
	TIM_OCInitTypeDef  TIM_OCInitStructrue;                //中断通道结构体定义
	RCC_APB2PeriphClockCmd(RCC_APB2Periph_GPIOB, ENABLE);    //开启GPIO端口时钟
	RCC_APB2PeriphClockCmd(RCC_APB1Periph_TIM4, ENABLE);    //开启定时器时钟

	GPIO_InitStructrue.GPIO_Mode=GPIO_Mode_AF_PP;            //引脚定义设置
	GPIO_InitStructrue.GPIO_Pin	=GPIO_Pin_6|GPIO_Pin_7|GPIO_Pin_8|GPIO_Pin_9;                //引脚定义设置
	GPIO_InitStructrue.GPIO_Speed =	GPIO_Speed_50MHz;        //引脚定义设置
	GPIO_Init(GPIOB, &GPIO_InitStructrue);                    //引脚定义设置

	TIM_TimeBaseInitStructrue.TIM_ClockDivision=0;                //定时器初始化设置
	TIM_TimeBaseInitStructrue.TIM_CounterMode=TIM_CounterMode_Up;//定时器初始化设置
	TIM_TimeBaseInitStructrue.TIM_Period=per;                    //定时器初始化设置
	TIM_TimeBaseInitStructrue.TIM_Prescaler=psc;                  //定时器初始化设置
	TIM_TimeBaseInit(TIM4,&TIM_TimeBaseInitStructrue);            //定时器初始化设置

	TIM_OCInitStructrue.TIM_OCMode=TIM_OCMode_PWM1;                //PWM1模式
	TIM_OCInitStructrue.TIM_OCPolarity=TIM_OCPolarity_High;        //设置PWM输出极性high
	TIM_OCInitStructrue.TIM_OutputState=TIM_OutputState_Enable;    //PWM比较输出使能
	TIM_OCInitStructrue.TIM_Pulse=0;                                //初始化脉宽为0

	TIM_OC1Init(TIM4,&TIM_OCInitStructrue);                        //初始化通道一
	TIM_OC1PreloadConfig(TIM4,TIM_OCPreload_Enable);
	
	TIM_OC2Init(TIM4,&TIM_OCInitStructrue);                        //初始化通道二
	TIM_OC2PreloadConfig(TIM4,TIM_OCPreload_Enable);
	
	TIM_OC3Init(TIM4,&TIM_OCInitStructrue);                        //初始化通道三
	TIM_OC3PreloadConfig(TIM4,TIM_OCPreload_Enable);
	
	TIM_OC4Init(TIM4,&TIM_OCInitStructrue);                        //初始化通道四
	TIM_OC4PreloadConfig(TIM4,TIM_OCPreload_Enable);
	
	TIM_ARRPreloadConfig(TIM4,ENABLE);    //使能TIM4在ARR上的预装载寄存器
	TIM_Cmd(TIM4, ENABLE);
}


void EN_Step_Motor(int motor_num,int EN)
{
	if(EN==1)//开启
	{
		if(motor_num==1)
		{
			 GPIO_SetBits(GPIOC,GPIO_Pin_1);
		}
		if(motor_num==2)
		{
			 GPIO_SetBits(GPIOC,GPIO_Pin_2);
		}
		if(motor_num==3)
		{
			 GPIO_SetBits(GPIOC,GPIO_Pin_3);
		}
		if(motor_num==4)
		{
			 GPIO_SetBits(GPIOC,GPIO_Pin_4);
		}
	}
	if(EN==0)
	{
		if(motor_num==1)
		{
			 GPIO_ResetBits(GPIOC,GPIO_Pin_1);
		}
		if(motor_num==2)
		{
			 GPIO_ResetBits(GPIOC,GPIO_Pin_2);
		}
		if(motor_num==3)
		{
			 GPIO_ResetBits(GPIOC,GPIO_Pin_3);
		}
		if(motor_num==4)
		{
			 GPIO_ResetBits(GPIOC,GPIO_Pin_4);
		}
	}
	if(EN==3)//全开
	{
		GPIO_SetBits(GPIOC,GPIO_Pin_1);
		GPIO_SetBits(GPIOC,GPIO_Pin_2);
		GPIO_SetBits(GPIOC,GPIO_Pin_3);
		GPIO_SetBits(GPIOC,GPIO_Pin_4);
	}
	if(EN==4)//全关
	{
		GPIO_ResetBits(GPIOC,GPIO_Pin_1);
		GPIO_ResetBits(GPIOC,GPIO_Pin_2);
		GPIO_ResetBits(GPIOC,GPIO_Pin_3);
		GPIO_ResetBits(GPIOC,GPIO_Pin_4);
	}
}

void Dir_change(int motor_num,int Dir)
{
	if(Dir==1)//顺时针转
	{
		if(motor_num==1)
		{
			 GPIO_SetBits(GPIOG,GPIO_Pin_1);
		}
		if(motor_num==2)
		{
			 GPIO_SetBits(GPIOG,GPIO_Pin_2);
		}
		if(motor_num==3)
		{
			 GPIO_SetBits(GPIOG,GPIO_Pin_3);
		}
		if(motor_num==4)
		{
			 GPIO_SetBits(GPIOG,GPIO_Pin_4);
		}
	}
	if(Dir==-1)//逆时针转
	{
		if(motor_num==1)
		{
			 GPIO_ResetBits(GPIOG,GPIO_Pin_1);
		}
		if(motor_num==2)
		{
			 GPIO_ResetBits(GPIOG,GPIO_Pin_2);
		}
		if(motor_num==3)
		{
			 GPIO_ResetBits(GPIOG,GPIO_Pin_3);
		}
		if(motor_num==4)
		{
			 GPIO_ResetBits(GPIOG,GPIO_Pin_3);
		}
	}
}

//设置脉冲宽度
void pulse(int motor_num,int angle)//下面函数调用
{
	if(motor_num==1)
	{
		TIM4->CCR1=angle;
	}
	if(motor_num==2)
	{
		TIM4->CCR2=angle;
	}
	if(motor_num==3)
	{
		TIM4->CCR3=angle;
	}
	if(motor_num==4)
	{
		TIM4->CCR4=angle;
	}
}

//int pul =156;    //默认32细分下每秒一圈，对应TIM8->ARR的值
//按键更改脉冲频率调速
//button_num为按键
//pul为脉冲宽度
void change_pulse(int motor_num,int pul)    //更改脉冲频率函数，进而改变速度,如果pul=2*pul则，可以让电机停下来
{
	TIM8->ARR=pul;
	pulse(motor_num,pul/2);            //脉冲宽度为0.5，输出标准方波
 
}

//per==arr
void Stop_Stepper(int motor_num,u16 arr)//向上计数，高电平有效，那如果比较值设置最大，一直输出低电平，就停止
{
	//通过设置比较值为最大值，脉宽为0，使步进电机停止
	if(motor_num==1)
		{
			 TIM_SetCompare1(TIM4,arr);//相当于设置CCR,
		}
		if(motor_num==2)
		{
			 TIM_SetCompare2(TIM4,arr);
		}
		if(motor_num==3)
		{
			 TIM_SetCompare3(TIM4,arr);
		}
		if(motor_num==4)
		{
			 TIM_SetCompare4(TIM4,arr);
		}
}

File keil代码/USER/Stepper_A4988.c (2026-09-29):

#include "Stepper_A4988.h"
/*GPIO_motornum和GPIOx用于选择电机，GPIO_direction用于选择电机方向，dir：0为逆1为正，k为90°的倍数*/

//每次 0.1°
#include "stm32f10x.h"                  // Device header
void MOTOR_Init()
{
	GPIO_InitTypeDef GPIO_InitStructure;
  RCC_APB2PeriphClockCmd(Motor_RCC,ENABLE);
	 RCC_APB2PeriphClockCmd(Motor_RCC1,ENABLE);
	//Motor初始化
	GPIO_InitStructure.GPIO_Pin = Motor1_STEP|Motor1_DIR|Motor2_STEP|Motor2_DIR;
	GPIO_InitStructure.GPIO_Mode=GPIO_Mode_Out_PP;
	GPIO_InitStructure.GPIO_Speed = GPIO_Speed_50MHz;
	GPIO_Init(Motor_GPIO,&GPIO_InitStructure);	// 初始化GPIOF
	GPIO_ResetBits(Motor_GPIO,Motor1_STEP);			//初始化GPIOF_12输出低电平
	GPIO_ResetBits(Motor_GPIO,Motor1_DIR);			//初始化GPIOF_13输出低电平
	GPIO_ResetBits(Motor_GPIO,Motor2_STEP);			//初始化GPIOF_14输出低电平
	GPIO_ResetBits(Motor_GPIO,Motor2_DIR);			//初始化GPIOF_15输出低电平
	
	GPIO_InitStructure.GPIO_Pin = Motor3_STEP|Motor3_DIR|Motor4_STEP|Motor4_DIR;
	GPIO_InitStructure.GPIO_Mode=GPIO_Mode_Out_PP;
	GPIO_InitStructure.GPIO_Speed = GPIO_Speed_50MHz;
	GPIO_Init(Motor_GPIO1,&GPIO_InitStructure);	// 初始化GPIOF
	GPIO_ResetBits(Motor_GPIO1,Motor3_STEP);			//初始化GPIOF_12输出低电平
	GPIO_ResetBits(Motor_GPIO1,Motor3_DIR);			//初始化GPIOF_13输出低电平
	GPIO_ResetBits(Motor_GPIO1,Motor4_STEP);			//初始化GPIOF_14输出低电平
	GPIO_ResetBits(Motor_GPIO1,Motor4_DIR);			//初始化GPIOF_15输出低电平
}
//motor 1-4  motor 0,1各表示一个方向，motor_step表示转多少个90度
void Stepgo(unsigned int motor_num,unsigned int motor_dir,unsigned int motor_step)//一个step转90度
{
	unsigned int i;
	if(motor_num==1)
	{
		switch(motor_dir)
		{
			case 0 : GPIO_SetBits(Motor_GPIO,Motor1_DIR); break; 
			case 1 : GPIO_ResetBits(Motor_GPIO,Motor1_DIR); break; 
			default : break; 
		}
		for(i=0;i<motor_step;i++)
		{
			GPIO_SetBits(Motor_GPIO,Motor1_STEP);
			delay_us(200);									
			GPIO_ResetBits(Motor_GPIO,Motor1_STEP);
			delay_us(200);
		}
	}
	
	if(motor_num==2)//下面
	{
		switch(motor_dir)
		{
			case 0 : GPIO_SetBits(Motor_GPIO,Motor2_DIR); break; 
			case 1 : GPIO_ResetBits(Motor_GPIO,Motor2_DIR); break; 
			default : break; 
		}
		for(i=0;i<motor_step;i++)
		{
			GPIO_SetBits(Motor_GPIO,Motor2_STEP);
			delay_us(1000);									//周期1.3ms
			GPIO_ResetBits(Motor_GPIO,Motor2_STEP);
			delay_us(1000);
		}
	}
	if(motor_num==3)//上
	{
		switch(motor_dir)
		{
			case 0 : GPIO_SetBits(Motor_GPIO,Motor3_DIR); break; 
			case 1 : GPIO_ResetBits(Motor_GPIO,Motor3_DIR); break; 
			default : break; 
		}
		for(i=0;i<motor_step;i++)
		{
			GPIO_SetBits(Motor_GPIO1,Motor3_STEP);
			delay_us(500);									//周期1.3ms
			GPIO_ResetBits(Motor_GPIO1,Motor3_STEP);
			delay_us(500);
		}
	}
	if(motor_num==4)
	{
		switch(motor_dir)
		{
			case 0 : GPIO_SetBits(Motor_GPIO1,Motor4_DIR); break; 
			case 1 : GPIO_ResetBits(Motor_GPIO1,Motor4_DIR); break; 
			default : break; 
		}
		for(i=0;i<motor_step;i++)
		{
			GPIO_SetBits(Motor_GPIO1,Motor4_STEP);
			delay_ms(1);									//周期1.3ms
			GPIO_ResetBits(Motor_GPIO1,Motor4_STEP);
			delay_ms(1);
		}
	}
}

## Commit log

2026-09-29 多功能豆类播种机
    [42丝杆步进电机.sldprt, 42步进电机.sldprt, 42电机平架.SLDPRT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]
2026-09-30 修改readme
